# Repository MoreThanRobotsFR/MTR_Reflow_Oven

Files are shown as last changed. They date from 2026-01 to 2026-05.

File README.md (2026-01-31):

# MTR Reflow Oven

**MTR Reflow Oven** is a comprehensive hardware and firmware project designed to control a reflow oven for PCB assembly. This repository contains the custom PCB design, the firmware for the RP2040 microcontroller, and a companion PC configurator tool.

## Repository Structure

*   **`Firmware/`**
    *   **`mtr_reflow_oven/`**: The core C++ firmware for the RP2040 microcontroller. It handles temperature PID control, user interface (LVGL), and profile management.
    *   **`Configurator/`**: A Python-based desktop application for creating and managing reflow profiles and configuring device settings.
*   **`Hardware/`**
    *   Contains the KiCad project files (`.kicad_pcb`, `.kicad_sch`) for the custom controller board.

## Getting Started

### Hardware
The `Hardware` directory contains the complete KiCad project. You can open `Hardware/MTR_Reflow_Oven.kicad_pro` with [KiCad 8.0+](https://www.kicad.org/) to view or modify the schematics and PCB layout.

### Firmware (RP2040)
The firmware is built using the Raspberry Pi Pico SDK.

**Prerequisites:**
*   CMake
*   Arm GNU Toolchain (`arm-none-eabi-gcc`)
*   Pico SDK

**Build Instructions:**
1.  Navigate to the firmware directory:
    ```bash
    cd Firmware/mtr_reflow_oven
    ```
2.  Create a build directory:
    ```bash
    mkdir build
    cd build
    ```
3.  Configure and build:
    ```bash
    cmake ..
    make
    ```
4.  Flash the resulting `.uf2` file to your RP2040 device.

### Configurator (PC Software)
The configurator allows you to easily edit reflow profiles.

**Prerequisites:**
*   Python 3.x
*   Required packages (see `requirements.txt` if available, or manually install common dependencies like `pyserial`, `tkinter`/`customtkinter`).

**Running:**
```bash
cd Firmware/Configurator
python reflow_configurator.py
```

## License
[License Information Here]

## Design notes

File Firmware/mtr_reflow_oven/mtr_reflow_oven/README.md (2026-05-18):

# MTR Reflow Oven Controller

Firmware for the MoreThanRobotsFR (MTR) Reflow Oven, based on the Raspberry Pi Pico (RP2040).

## Overview

This project implements a complete reflow oven controller utilizing FreeRTOS for task management and LVGL for the graphical user interface. It is designed to run on the RP2040 microcontroller and controls up to two solid-state relays (SSRs) to manage heating elements using a custom PID control loop.

## Key Features

- **Microcontroller**: RP2040 (Raspberry Pi Pico)
- **Real-Time OS**: FreeRTOS
- **User Interface**: 
  - SPI Display (e.g., ST7796) driven by the LVGL graphics library
  - Navigation via Rotary Encoder and tactile buttons
  - Multi-screen UI (Dashboard, Profile Selection, Settings, Manual Control)
- **Temperature Sensing**: Support for up to two MCP9600 Thermocouple Amplifiers via I2C
- **Heater Control**: 
  - Dual PWM outputs for SSR (Solid State Relay) control
  - Configurable PID loop for precise temperature tracking
- **Storage**: SD Card support (FatFS over SPI) for loading JSON-based reflow profiles and saving system configurations
- **Feedback**: 
  - WS2812B RGB LED status indicator (using PIO)
  - Passive buzzer for audible alerts

## Hardware Configuration

The pinout and hardware settings are defined in `board_config.h`. 

Key pin assignments:
- **Display (SPI0)**: SCK (18), MOSI (19), MISO (20), CS (21), DC (25), RST (24), Backlight (23)
- **SD Card (SPI0)**: CS (22)
- **Sensors (I2C0)**: SDA (4), SCL (5)
- **Heaters**: SSR1 (26), SSR2 (27)
- **Inputs**: 
  - Rotary Encoder: DT (6), CLK (7), SW (8)
  - Buttons: BTN1 (0), BTN2 (1)
- **Outputs**: WS2812B LED (9), Buzzer (28)

## Build Instructions

This project uses CMake and requires the Raspberry Pi Pico SDK.

1. Ensure you have the [Raspberry Pi Pico SDK](https://github.com/raspberrypi/pico-sdk) installed and the `PICO_SDK_PATH` environment variable set.
2. Initialize and build the project:
   ```bash
   mkdir build
   cd build
   cmake ..
   make # or ninja, depending on your environment
   ```
3. Flash the resulting `.uf2` file to your Pico by holding the BOOTSEL button while plugging it in, then dragging the file to the `RPI-RP2` drive.

## Configuration & Profiles

- **System Config**: Settings such as PID tuning parameters, display orientation, and hardware flags are stored on the SD Card at `/config/system.json`.
- **Reflow Profiles**: Custom temperature profiles (e.g., SAC305) can be loaded from the SD Card in JSON format. They define specific heating segments (Preheat, Soak, Ramp, Reflow) with target temperatures and durations.

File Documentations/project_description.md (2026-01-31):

# Projet : Four de Refusion de Précision (RP2040, FreeRTOS, LVGL)

## 1. Objectif Global

Transformer un four via un contrôleur basé sur **RP2040** en une station de refusion performante. Le système se distingue par :

* Un **suivi thermique haute précision** via capteurs I2C dédiés (MCP9600).
* Une gestion **multi-zones** (2 éléments chauffants pilotables indépendamment).
* Une architecture logicielle **FreeRTOS** robuste (séparation UI / Contrôle / Sécurité).
* Des **profils de refusion flexibles** (nombre illimité de paliers/segments via SD).
* Une interface graphique (UI) fluide sous **LVGL**.

## 2. Matériel & Interfaces (Mise à jour Câblage Réel)

### 2.1 Cœur & Bus

* **MCU** : Raspberry Pi RP2040 (Dual-core ARM Cortex-M0+ @ 133MHz).
* **Bus SPI0** (Partagé) : Écran TFT + Carte SD. Nécessite une gestion rigoureuse des Chip Select (CS) et du timing.
* **Bus I2C** : Capteurs de température MCP9600 (Adresses distinctes requises).
* **Bus 1-Wire** : Sonde d'ambiance/calibration DS18B20.

### 2.2 Entrées Utilisateur (HMI)

Le panneau de commande dispose de **4 boutons physiques** et **1 encodeur rotatif** :

* **Boutons Nav** : 3 boutons dédiés (GPIO 0, 1, 2) pour actions rapides (Start, Stop, Menu) ou navigation contextuelle.
* **Encodeur** : Rotation (GPIO 6, 7) + Bouton intégré (GPIO 8) pour le réglage fin des valeurs.

### 2.3 Affichage & Feedback

* **Écran** : Module SPI (ex: ILI9341, ST7789) avec contrôle complet (Backlight, DC, Reset).
* **LEDs Statut** : Ruban/Module **WS2812B** (Smart LED) sur GPIO 9 pour coder l'état (Bleu=Cool, Orange=Preheat, Rouge=Reflow, Vert=Complete).
* **Buzzer** : Buzzer actif ou passif (PWM) sur GPIO 28 pour alarmes et bips IHM.

### 2.4 Thermométrie & Puissance

* **Capteur T1 (Principal)** : MCP9600 (Thermocouple convertisseur I2C). Haute précision, compensation de soudure froide intégrée.
* **Capteur T2 (Optionnel)** : MCP9600 secondaire. Le système doit scanner l'I2C au démarrage ; si absent, le four fonctionne en mode "Single Sensor".
* **Sécurité Hardware** : Les broches d'alerte (Alert 1-4) des MCP9600 sont câblées aux GPIOs RP2040. Cela permet de déclencher des interruptions immédiates en cas de surchauffe, sans attendre la boucle de lecture I2C.
* **Actionneurs Chauffe** :
* **SSR 1 (GPIO 26)** : Élément chauffant principal.
* **SSR 2 (GPIO 27)** : Élément chauffant secondaire (Boost ou zone distincte).

---

## 3. Mapping GPIO Définitif

Ce tableau respecte scrupuleusement le fichier `Extrait du cablage réal.csv`.

| GPIO | Fonction Label | Type Signal | Description Technique / Usage |
| --- | --- | --- | --- |
| **0** | BTN1 | Input (IRQ) | Bouton Façade 1 (Navigation/Action) |
| **1** | BTN2 | Input (IRQ) | Bouton Façade 2 (Navigation/Action) |
| **2** | BTN3 | Input (IRQ) | Bouton Façade 3 (Navigation/Action) |
| **3** | SD_CD | Input | **SD Card Detect**. Low = Carte présente. |
| **4** | I2C_SDA | I2C Data | Bus I2C pour MCP9600 (Sensor 1 & 2). |
| **5** | I2C_SCL | I2C Clock | Bus I2C pour MCP9600 (Sensor 1 & 2). |
| **6** | ROT_DT | Input (IRQ) | Encodeur Phase B (Data). |
| **7** | ROT_CLK | Input (IRQ) | Encodeur Phase A (Clock). |
| **8** | ROT_BTN | Input (IRQ) | Bouton poussoir de l'encodeur. |
| **9** | WS_LED | Output (Data) | Signal **WS2812B** (Neopixel) pour feedback visuel. |
| **10** | T1_ALT4 | Input (IRQ) | MCP9600 T1 Alert 4 (Seuil critique Hard). |
| **11** | T1_ALT3 | Input (IRQ) | MCP9600 T1 Alert 3. |
| **12** | T1_ALT2 | Input (IRQ) | MCP9600 T1 Alert 2. |
| **13** | T1_ALT1 | Input (IRQ) | MCP9600 T1 Alert 1 (Seuil pré-alerte). |
| **14** | T2_ALT4 | Input (IRQ) | MCP9600 T2 Alert 4 (Si T2 présent). |
| **15** | T2_ALT3 | Input (IRQ) | MCP9600 T2 Alert 3. |
| **16** | T2_ALT2 | Input (IRQ) | MCP9600 T2 Alert 2. |
| **17** | T2_ALT1 | Input (IRQ) | MCP9600 T2 Alert 1. |
| **18** | SPI_SCK | SPI0 Clock | Horloge partagée Écran + SD. |
| **19** | SPI_MOSI | SPI0 TX | Données sortantes (Vers Écran + SD). |
| **20** | SPI_MISO | SPI0 RX | Données entrantes (Depuis SD uniquement). |
| **21** | SCR_CS | Output | **Chip Select Écran**. |
| **22** | SD_CS | Output | **Chip Select SD Card** (Note: Label SD_DAT3/CS). |
| **23** | SCR_BL | Output (PWM) | Backlight écran (dimming possible). |
| **24** | SCR_RST | Output | Reset Hardware Écran. |
| **25** | SCR_DC | Output | Data/Command Écran. |
| **26** | HEAT1 | Output (PWM) | Pilotage SSR 1 (Résistance principale). |
| **27** | HEAT2 | Output (PWM) | Pilotage SSR 2 (Résistance secondaire). |
| **28** | BUZZER | Output (PWM) | Buzzer (Tones passifs ou Active High). |
| **29** | 1-WIRE | In/Out | Bus OneWire pour DS18B20 (Ambiante/Ref). |

---

## 4. Fonctionnalités Logicielles Avancées

### 4.1 Profils Thermiques Dynamiques ("Flexible Steps")

Contrairement à une structure rigide (Preheat/Soak/Reflow), le moteur de profil lira une liste de **segments**. Cela permet de créer des profils complexes (ex: recuit lent, double refusion, séchage PCB).

* **Types de segments supportés** :
* `RAMP` : Atteindre une T° cible avec une pente donnée (°C/s).
* `STEP` : Saut immédiat de consigne (step response).
* `HOLD` : Maintenir la T° pendant X secondes.

* **Chargement** : Parsing JSON depuis la carte SD.

### 4.2 Gestion Hardware "Safe"

* **Détection T2** : Au boot, ping I2C sur l'adresse de T2. Si ACK → Activation T2. Sinon → Ignorer T2 et masquer les infos T2 sur l'UI.
* **Interruptions MCP9600** : Configuration des registres MCP9600 pour trigger les pins ALT (GPIO 10-17) si T° > 260°C (hard limit). Une ISR sur ces pins coupe immédiatement les SSR, bypassant le RTOS en cas de plantage tâche.

### 4.3 Contrôle PID & PWM

* **PWM Lente** : Les SSR Zéro-crossing n'aiment pas le PWM rapide. On utilisera un PWM logiciel ou hardware à très basse fréquence (ex: 2Hz à 5Hz) ou un algorithme de Bresenham sur une base de temps de 100ms.
* **Dual PID** : Possibilité d'avoir des paramètres PID différents pour SSR1 et SSR2, ou de coupler SSR2 en mode "Esclave" (ex: SSR2 = 80% de SSR1 pour homogénéiser).

---

## 5. Architecture Système (FreeRTOS)

L'absence de Servo simplifie la sortie, mais l'ajout de la gestion SPI partagée et des interruptions MCP demande de la rigueur.

### 5.1 Tâches (Tasks)

| Priorité | Tâche | Stack | Description |
| --- | --- | --- | --- |
| **High (5)** | `Alert_Handling` | Minimal | Traitement des interruptions GPIO (MCP9600 ALT pins) et Watchdog. Arrêt d'urgence. |
| **High (4)** | `Sensor_Poller` | 3 KB | Lecture I2C (MCP9600) et 1-Wire. Conversion des données brutes. Gestion des erreurs de lecture. |
| **Med (3)** | `PID_Loop` | 2 KB | Calcul de l'erreur, PID, output PWM vers SSRs. Cycle fixe (ex: 200ms). |
| **Med (3)** | `App_Logic` | 4 KB | Machine d'états (Idle, Run, Cooldown). Orchestrateur principal. Parseur JSON. |
| **Low (2)** | `GUI_Task` | 8 KB | Gestion LVGL, rafraîchissement écran, lecture inputs (Queue events). |
| **Low (1)** | `Disk_Logger` | 4 KB | Écriture asynchrone des logs CSV sur SD (pour ne pas bloquer les tâches critiques). |

### 5.2 Gestion des Ressources (Mutex & Queues)

* **`mtx_SPI0` (CRITIQUE)** : L'écran et la SD sont sur le même bus.
* La tâche `GUI_Task` doit prendre ce mutex avant de dessiner.
* La tâche `Disk_Logger` (et le chargeur de profil `App_Logic`) doit prendre ce mutex avant tout accès fichier.
* *Stratégie* : Utiliser le DMA pour l'écran pour minimiser le temps de blocage du CPU, mais le Mutex reste obligatoire pour l'accès bus.

* **`mtx_I2C`** : Protection d'accès aux capteurs MCP9600.
* **`q_SensorData`** : Structure contenant `{temp1, temp2, temp_amb, status_flags}` envoyée par *Sensor_Poller* vers *PID_Loop* et *GUI*.

---

## 6. Structure des Fichiers (Carte SD)

### 6.1 Format de Profil (`/profiles/sac305.json`)

Structure mise à jour pour permettre un nombre illimité d'étapes.

```json
{
  "meta": {
    "name": "SAC305 Standard",
    "description": "Profil sans plomb classique",
    "author": "User"
  },
  "safety": {
    "max_temp": 255,
    "max_slope": 3.0
  },
  "segments": [
    { "type": "ramp", "end_temp": 150, "slope": 1.5, "note": "Preheat" },
    { "type": "hold", "duration_s": 90,  "temp": 150, "note": "Soak" },
    { "type": "ramp", "end_temp": 217, "slope": 2.5, "note": "Ramp to Reflow" },
    { "type": "ramp", "end_temp": 245, "slope": 1.0, "note": "Peak Reflow" },
    { "type": "hold", "duration_s": 20,  "temp": 245, "note": "Liquid Time" },
    { "type": "ramp", "end_temp": 50,  "slope": -2.0, "note": "Cooling" }
  ]
}

```

### 6.2 Fichier de Configuration (`/config/system.json`)

```json
{
  "hardware": {
    "enable_sensor2_check": true,
    "screen_orientation": 1,
    "buzzer_volume": 80
  },
  "pid_params": {
    "ssr1": { "kp": 15.0, "ki": 0.05, "kd": 80.0 },
    "ssr2": { "kp": 10.0, "ki": 0.05, "kd": 50.0 }
  },
  "calibration": {
    "t1_offset": -1.5,
    "t2_offset": 0.0
  }
}

```

---

## 7. Machine d'États Révisée

1. **INIT** : Setup GPIO, détection T2 (I2C), montage SD (SD_CD check), init écran.
2. **IDLE** : Attente utilisateur. Lecture T° ambiante. Affichage liste profils.
3. **PRE_CHECK** : Vérification intégrité capteurs (pas de court-circuit MCP9600), porte fermée (si capteur ajouté futur), température de départ < 50°C.
4. **RUNNING** : Exécution du tableau `segments`.
* Calcul de la `Target_Temp` courante par interpolation temporelle.
* PID calcule `% Power`.
* Update Graphique.

5. **COOLDOWN** : Fin du profil ou annulation manuelle. SSR OFF. Affichage "HOT" en rouge/orange sur LED WS2812B tant que T > 50°C. Buzzer intermittent.
6. **FAULT** : Déclenché par ISR (Pins ALT) ou timeout logiciel. SSR OFF hard (GPIO low). Buzzer continu. Log de l'erreur.

---

## 8. Roadmap Technique & Étapes Clés

1. **Low-Level Drivers (HAL)** :
* Valider le SPI partagé : Dessiner sur l'écran puis écrire un fichier texte sur la SD dans une boucle simple sans corruption.
* Valider I2C MCP9600 : Lire la T° et configurer les registres d'alerte pour tester le déclenchement des GPIO 10-13.

2. **Intégration FreeRTOS Base** :
* Lancer LVGL dans sa tâche.
* Lancer le logger SD dans sa tâche.
* Vérifier que les inputs (Encodeur/Boutons) via interruptions mettent bien à jour l'UI.

3. **Moteur Thermique** :
* Implémenter le parseur de segments JSON.
* Coder la boucle PID.
* Tester avec une consigne fixe (Mode Manuel) avant de lancer un profil.

4. **Raffinement** :
* Logique de détection automatique du Capteur 2.
* Effets LED WS2812B (Dégradés de couleur selon T°).
* Tuning PID.

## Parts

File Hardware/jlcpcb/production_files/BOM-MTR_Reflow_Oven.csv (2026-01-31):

Comment | Designator | Footprint | LCSC | Quantity
0.1uF | C17,C18,C19,C23,C24,C3,C4 | R_0402_1005Metric | C60474 | 7
100R | R16,R17,R19,R20 | R_0402_1005Metric | C106232 | 4
100nF | C10,C11,C12,C13,C14,C15,C16,C5,C6,C8 | C_0402_1005Metric | C1525 | 10
10k |  | R_0402_1005Metric | C60490 | 0
18p | C1,C2 | C_0402_1005Metric | C33149 | 2
1M | R18,R21 | R_0402_1005Metric | C138033 | 2
1k | R1,R5 | R_0402_1005Metric | C106235 | 2
1uF | C21,C22,C7,C9 | C_0402_1005Metric | C14445 | 4
27.4R | R2,R3 | R_0402_1005Metric | C31439 | 2
2M | R22,R23,R24,R25 | R_0402_1005Metric | C11512 | 4
4.7k | R10,R11,R13,R14,R15,R4,R7,R8,R9 | R_0402_1005Metric | C105871 | 9
5.1k | R26,R27 | R_0402_1005Metric | C105871 | 2
ABM8-272-T3 | Y1 | CRYSTAL-SMD_4P-L3.2-W2.5-BL | C20625731 | 1
AO3401A | Q1 | SOT-23-3 | C15127 | 1
B3F-4055 | SW4,SW5 | KEY-TH_4P-L12.0-W12.0-P5.00-LS13.4-EH | C84931 | 2
Boot | SW1 | SW-SMD_L4.0-W3.0-LS5.0 | C2888420 | 1
DS18B20 | U4 | TO-92_Inline | C9753 | 1
FST-9018 | BZ1 | BUZ-SMD_FST-9018 | C391035 | 1
MCP9600T-E/MX | U5,U6 | QFN-20-1EP_5x5mm_P0.65mm_EP3.35x3.35mm_ThermalVias | C623918 | 2
RP2040 | U1 | QFN-56-1EP_7x7mm_P0.4mm_EP3.2x3.2mm_ThermalVias | C2040 | 1
Reset | SW2 | SW-SMD_L4.0-W3.0-LS5.0 | C2888420 | 1
RotaryEncoder_Switch_MP | SW3 | SW-TH_EC11XXXXXXXX | C470742 | 1
TF-01A_C2889258 | Card1 | TF-SMD_TF-02 | C2889258 | 1
TLV76733DRVR | U3 | WSON-6_L2.0-W2.0-P0.65-TL-EP | C2848334 | 1
TPS22810DRVR | U7,U8 | WSON-6-1EP_2x2mm_P0.65mm_EP1x1.6mm | C527679 | 2
USB_C_Receptacle_USB2.0 | J2 | USB_C_Receptacle_HRO_TYPE-C-31-M-12 | C165948 | 1
W25Q128JVS | U2 | SOIC-8_5.3x5.3mm_P1.27mm | C97521 | 1
WS2812B-B/W | LED1,LED2 | LED-SMD_4P-L5.0-W5.0-TL_WS2812B-B | C2761795 | 2
PINHD_1x8_Male | J1 | PinHeader_1x08_P2.54mm_Vertical |  | 1

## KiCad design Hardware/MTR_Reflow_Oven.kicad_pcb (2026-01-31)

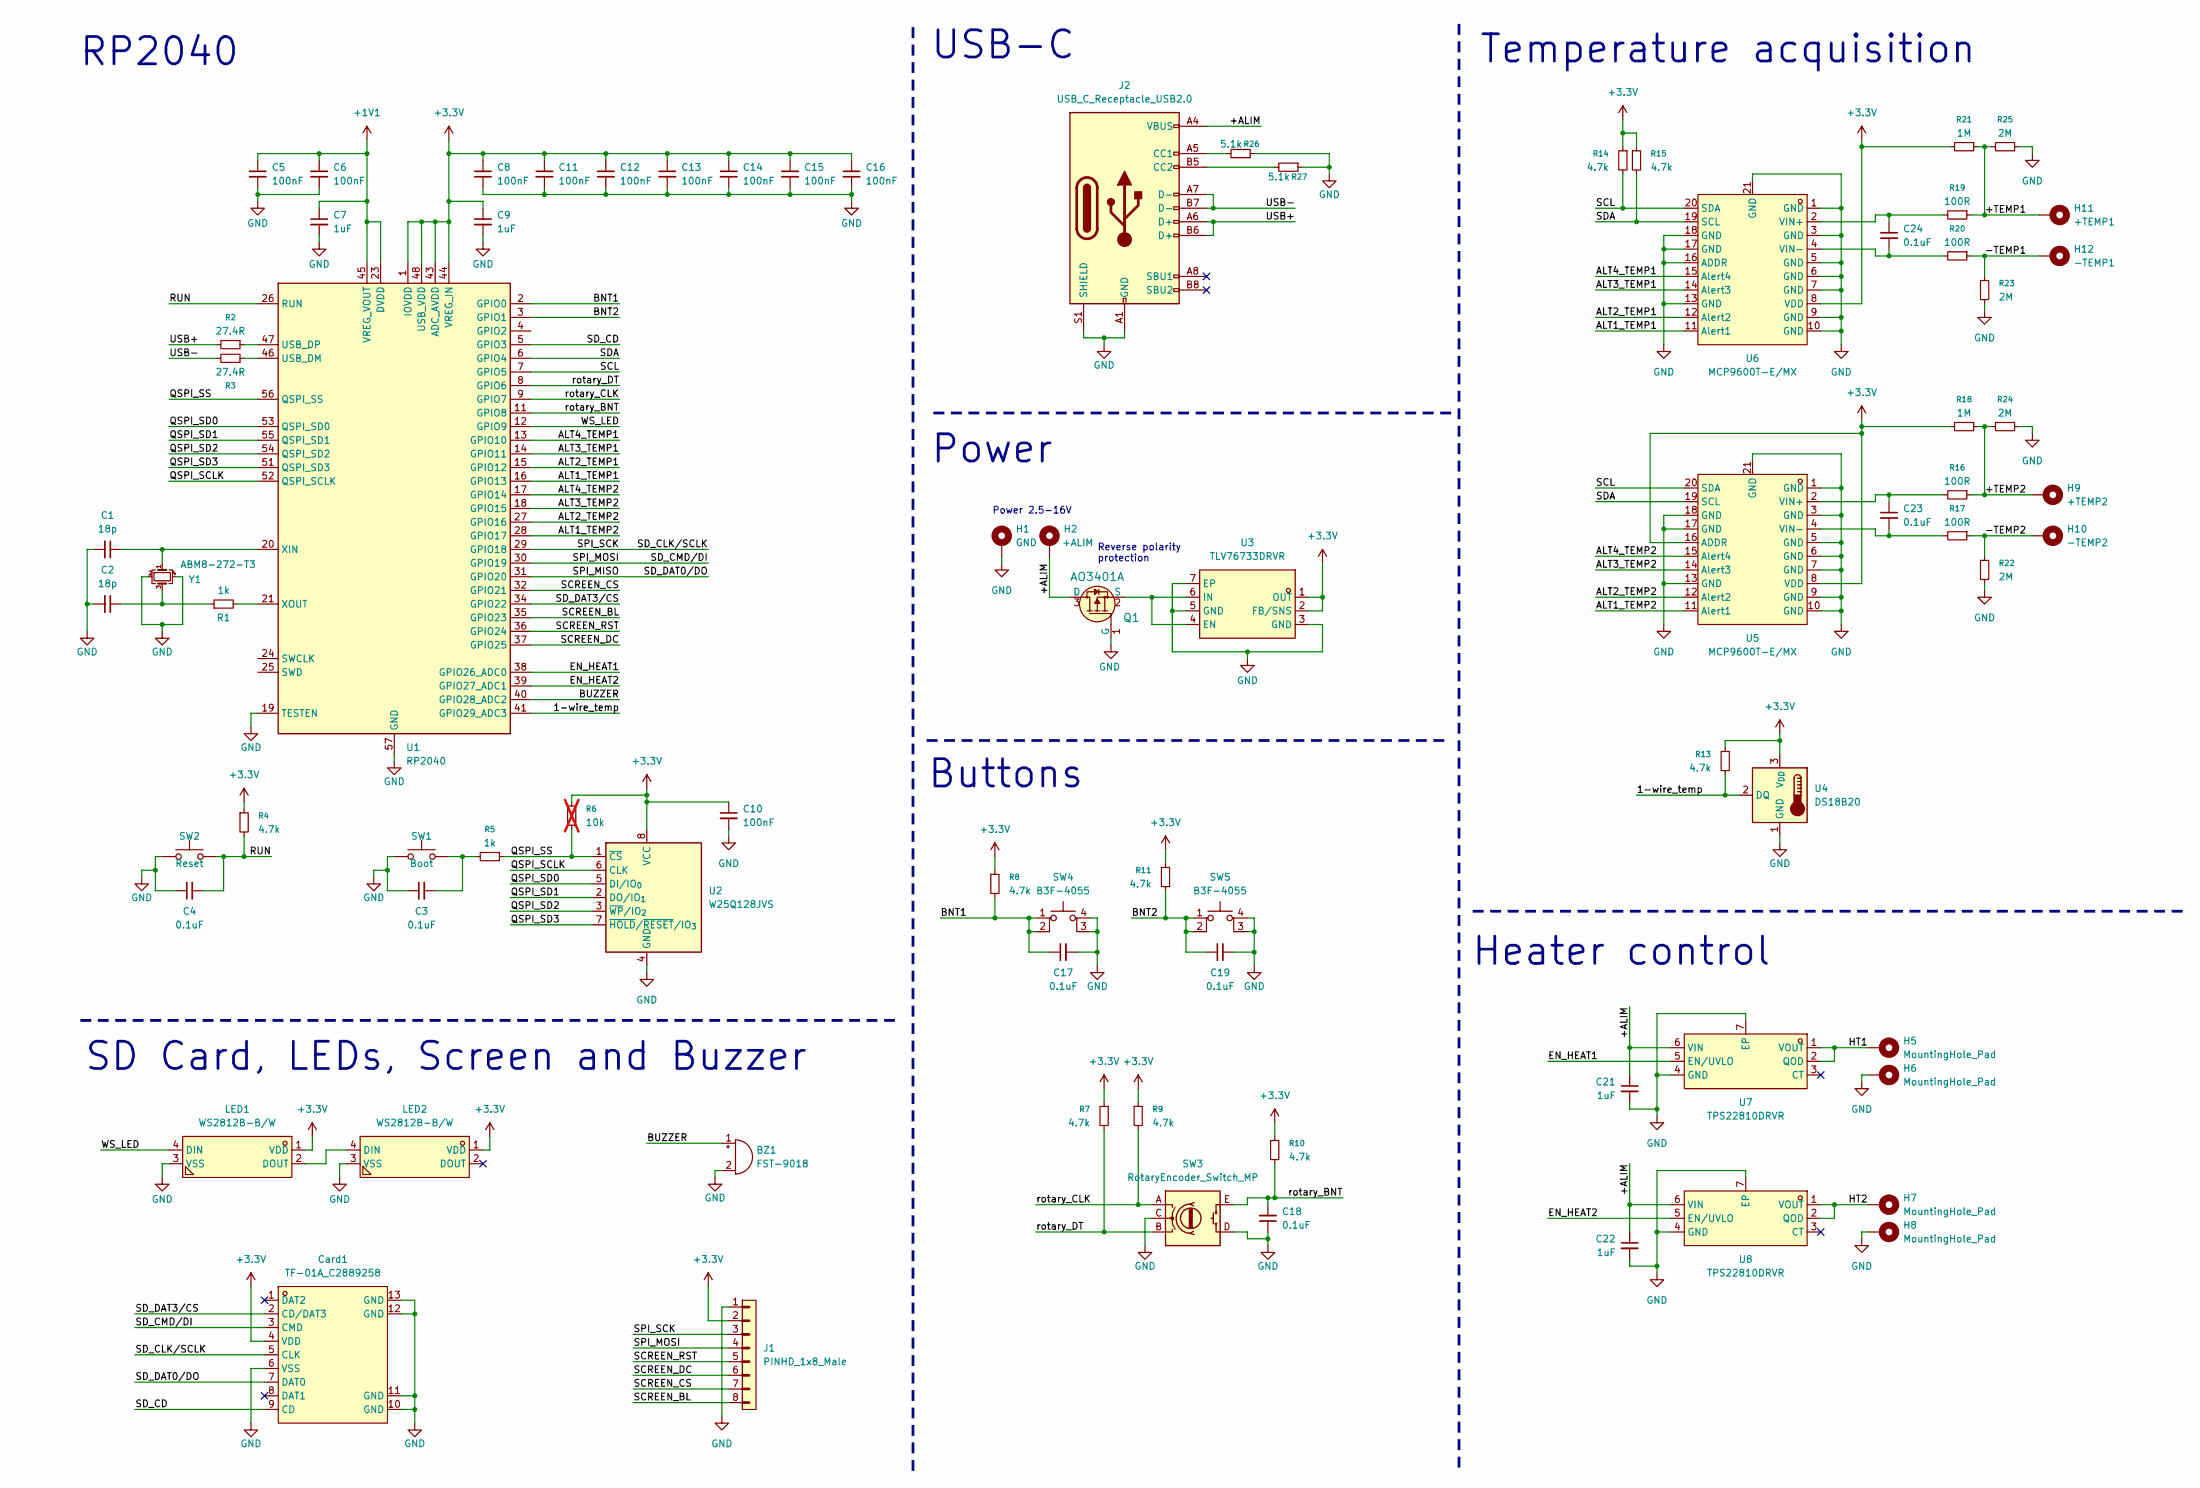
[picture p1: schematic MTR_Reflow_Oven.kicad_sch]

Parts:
BZ1: FST-9018; BUZ-SMD_FST-9018; LCSC Part C391035
C1, C2: 18p; C_0402_1005Metric; LCSC C33149
C3, C4, C17, C18, C19: 0.1uF; R_0402_1005Metric; LCSC C60474
C5, C6, C8, C10, C11, C12, C13, C14, C15, C16: 100nF; C_0402_1005Metric; LCSC C1525
C7, C9, C21, C22: 1uF; C_0402_1005Metric; LCSC C14445
C23, C24: 0.1uF; C_0402_1005Metric; LCSC C60474
Card1: TF-01A_C2889258; TF-SMD_TF-02; LCSC Part C2889258
H1: GND; MountingHole_2.2mm_M2_Pad
H2: +ALIM; MountingHole_2.2mm_M2_Pad
H5, H6, H7, H8: MountingHole_Pad; MountingHole_2.2mm_M2_Pad
H9: +TEMP2; MountingHole_2.2mm_M2_Pad
H10: -TEMP2; MountingHole_2.2mm_M2_Pad
H11: +TEMP1; MountingHole_2.2mm_M2_Pad
H12: -TEMP1; MountingHole_2.2mm_M2_Pad
J1: PINHD_1x8_Male; PinHeader_1x08_P2.54mm_Vertical
J2: USB_C_Receptacle_USB2.0; USB_C_Receptacle_HRO_TYPE-C-31-M-12; LCSC C165948
LED1, LED2: WS2812B-B/W; LED-SMD_4P-L5.0-W5.0-TL_WS2812B-B; LCSC Part C2761795
Q1: AO3401A; SOT-23-3; MPN AO3401A; Digi-Key_PN 785-1001-1-ND
R1, R5: 1k; R_0402_1005Metric; LCSC C106235
R2, R3: 27.4R; R_0402_1005Metric; LCSC C31439
R4, R7, R8, R9, R10, R11, R13, R14, R15: 4.7k; R_0402_1005Metric; LCSC C105871
R6: 10k; R_0402_1005Metric; LCSC C60490; not fitted
R16, R17, R19, R20: 100R; R_0402_1005Metric; LCSC C106232
R18, R21: 1M; R_0402_1005Metric; LCSC C138033
R22, R23, R24, R25: 2M; R_0402_1005Metric; LCSC C11512
R26, R27: 5.1k; R_0402_1005Metric; LCSC C105871
SW1: Boot; SW-SMD_L4.0-W3.0-LS5.0; LCSC C2888420
SW2: Reset; SW-SMD_L4.0-W3.0-LS5.0; LCSC C2888420
SW3: RotaryEncoder_Switch_MP; SW-TH_EC11XXXXXXXX; LCSC C470742
SW4, SW5: B3F-4055; KEY-TH_4P-L12.0-W12.0-P5.00-LS13.4-EH; LCSC C84931
U1: RP2040; QFN-56-1EP_7x7mm_P0.4mm_EP3.2x3.2mm_ThermalVias; LCSC C2040
U2: W25Q128JVS; SOIC-8_5.3x5.3mm_P1.27mm; LCSC C97521
U3: TLV76733DRVR; WSON-6_L2.0-W2.0-P0.65-TL-EP; LCSC Part C2848334
U4: DS18B20; TO-92_Inline; LCSC C9753
U5, U6: MCP9600T-E/MX; QFN-20-1EP_5x5mm_P0.65mm_EP3.35x3.35mm_ThermalVias; LCSC Part C623918
U7, U8: TPS22810DRVR; WSON-6-1EP_2x2mm_P0.65mm_EP1x1.6mm; LCSC Part C527679
Y1: ABM8-272-T3; CRYSTAL-SMD_4P-L3.2-W2.5-BL; LCSC C20625731

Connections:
+1V1: C5.1, C6.1, C7.1, U1.23 (DVDD), U1.45 (VREG_VOUT), U1.50 (DVDD)
+3.3V: C8.1, C9.1, C10.1, C11.1, C12.1, C13.1, C14.1, C15.1, C16.1, Card1.4 (VDD), J1.2, LED1.1 (VDD), LED2.1 (VDD), R4.1, R6.1, R7.1, R8.1, R9.1, R10.1, R11.1, R13.1, R14.1, R15.1, R18.2, R21.2, U1.1 (IOVDD), U1.10 (IOVDD), U1.22 (IOVDD), U1.33 (IOVDD), U1.42 (IOVDD), U1.43 (ADC_AVDD), U1.44 (VREG_IN), U1.48 (USB_VDD), U1.49 (IOVDD), U2.8 (VCC), U3.1 (OUT), U3.2 (FB/SNS), U4.3 (V_{DD}), U5.8 (VDD), U5.16 (ADDR), U6.8 (VDD)
/1-wire_temp: R13.2, U1.41 (GPIO29_ADC3), U4.2 (DQ)
/+ALIM: C21.1, C22.1, H2.1, J2.A4 (VBUS), J2.A9 (VBUS), J2.B4 (VBUS), J2.B9 (VBUS), Q1.3 (D), U7.6 (VIN), U8.6 (VIN)
/+TEMP1: H11.1, R19.1, R21.1, R25.2
/+TEMP2: H9.1, R16.1, R18.1, R24.2
/-TEMP1: H12.1, R20.1, R23.1
/-TEMP2: H10.1, R17.1, R22.1
/ALT1_TEMP1: U1.16 (GPIO13), U6.11 (Alert1)
/ALT1_TEMP2: U1.28 (GPIO17), U5.11 (Alert1)
/ALT2_TEMP1: U1.15 (GPIO12), U6.12 (Alert2)
/ALT2_TEMP2: U1.27 (GPIO16), U5.12 (Alert2)
/ALT3_TEMP1: U1.14 (GPIO11), U6.14 (Alert3)
/ALT3_TEMP2: U1.18 (GPIO15), U5.14 (Alert3)
/ALT4_TEMP1: U1.13 (GPIO10), U6.15 (Alert4)
/ALT4_TEMP2: U1.17 (GPIO14), U5.15 (Alert4)
/BNT1: C17.1, R8.2, SW4.1, SW4.2, U1.2 (GPIO0)
/BNT2: C19.1, R11.2, SW5.1, SW5.2, U1.3 (GPIO1)
/BUZZER: BZ1.1 (+), U1.40 (GPIO28_ADC2)
/EN_HEAT1: U1.38 (GPIO26_ADC0), U7.5 (EN/UVLO)
/EN_HEAT2: U1.39 (GPIO27_ADC1), U8.5 (EN/UVLO)
/HT1: H5.1, U7.1 (VOUT), U7.2 (QOD)
/HT2: H7.1, U8.1 (VOUT), U8.2 (QOD)
/QSPI_SCLK: U1.52 (QSPI_SCLK), U2.6 (CLK)
/QSPI_SD0: U1.53 (QSPI_SD0), U2.5 (DI/IO_{0})
/QSPI_SD1: U1.55 (QSPI_SD1), U2.2 (DO/IO_{1})
/QSPI_SD2: U1.54 (QSPI_SD2), U2.3 (~WP/IO_{2})
/QSPI_SD3: U1.51 (QSPI_SD3), U2.7 (~HOLD/~RESET/IO_{3})
/QSPI_SS: R5.1, R6.2, U1.56 (QSPI_SS), U2.1 (~CS)
/RUN: C4.2, R4.2, SW2.2, U1.26 (RUN)
/SCL: R14.2, U1.7 (GPIO5), U5.20 (SDA), U6.20 (SDA)
/SCREEN_BL: J1.8, U1.35 (GPIO23)
/SCREEN_CS: J1.7, U1.32 (GPIO21)
/SCREEN_DC: J1.6, U1.37 (GPIO25)
/SCREEN_RST: J1.5, U1.36 (GPIO24)
/SDA: R15.2, U1.6 (GPIO4), U5.19 (SCL), U6.19 (SCL)
/SD_CD: Card1.9 (CD), U1.5 (GPIO3)
/SD_CLK/SCLK: Card1.5 (CLK), J1.3, U1.29 (GPIO18)
/SD_CMD/DI: Card1.3 (CMD), J1.4, U1.30 (GPIO19)
/SD_DAT0/DO: Card1.7 (DAT0), U1.31 (GPIO20)
/SD_DAT3/CS: Card1.2 (CD/DAT3), U1.34 (GPIO22)
/USB+: J2.A6 (D+), J2.B6 (D+), R2.2
/USB-: J2.A7 (D-), J2.B7 (D-), R3.2
/WS_LED: LED1.4 (DIN), U1.12 (GPIO9)
/rotary_BNT: C18.2, R10.2, SW3.E (S1), U1.11 (GPIO8)
/rotary_CLK: R9.2, SW3.A, U1.9 (GPIO7)
/rotary_DT: R7.2, SW3.B, U1.8 (GPIO6)
GND: BZ1.2 (-), C1.2, C2.2, C3.1, C4.1, C5.2, C6.2, C7.2, C8.2, C9.2, C10.2, C11.2, C12.2, C13.2, C14.2, C15.2, C16.2, C17.2, C18.1, C19.2, C21.2, C22.2, Card1.6 (VSS), Card1.10 (GND), Card1.11 (GND), Card1.12 (GND), Card1.13 (GND), H1.1, H6.1, H8.1, J1.1, J2.A1 (GND), J2.A12 (GND), J2.B1 (GND), J2.B12 (GND), J2.S1 (SHIELD), LED1.3 (VSS), LED2.3 (VSS), Q1.1 (G), R22.2, R23.2, R24.1, R25.1, R26.1, R27.1, SW1.1, SW2.1, SW3.C, SW3.D (S2), SW4.3 (K), SW4.4 (A), SW5.3 (K), SW5.4 (A), U1.19 (TESTEN), U1.57 (GND), U2.4 (GND), U3.3 (GND), U3.5 (GND), U3.7 (EP), U4.1 (GND), U5.1 (GND), U5.3 (GND), U5.5 (GND), U5.6 (GND), U5.7 (GND), U5.9 (GND), U5.10 (GND), U5.13 (GND), U5.17 (GND), U5.18 (GND), U5.21 (GND), U6.1 (GND), U6.3 (GND), U6.5 (GND), U6.6 (GND), U6.7 (GND), U6.9 (GND), U6.10 (GND), U6.13 (GND), U6.16 (ADDR), U6.17 (GND), U6.18 (GND), U6.21 (GND), U7.4 (GND), U7.7 (EP), U8.4 (GND), U8.7 (EP), Y1.2, Y1.4
unnamed: C2.1, R1.1, Y1.3
unnamed: C3.2, R5.2, SW1.2
unnamed: J2.A5 (CC1), R26.2
unnamed: J2.B5 (CC2), R27.2
unnamed: LED1.2 (DOUT), LED2.4 (DIN)
unnamed: Q1.2 (S), U3.4 (EN), U3.6 (IN)
unnamed: R3.1, U1.46 (USB_DM)
unnamed: R2.1, U1.47 (USB_DP)
unnamed: C1.1, U1.20 (XIN), Y1.1
unnamed: R1.2, U1.21 (XOUT)
unnamed: C23.1, R16.2, U5.2 (VIN+)
unnamed: C23.2, R17.2, U5.4 (VIN-)
unnamed: C24.1, R19.2, U6.2 (VIN+)
unnamed: C24.2, R20.2, U6.4 (VIN-)

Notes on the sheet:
Power
Temperature acquisition
USB-C
Heater control
SD Card, LEDs, Screen and Buzzer
Reverse polarity protection
Buttons
Power 2.5-16V
RP2040

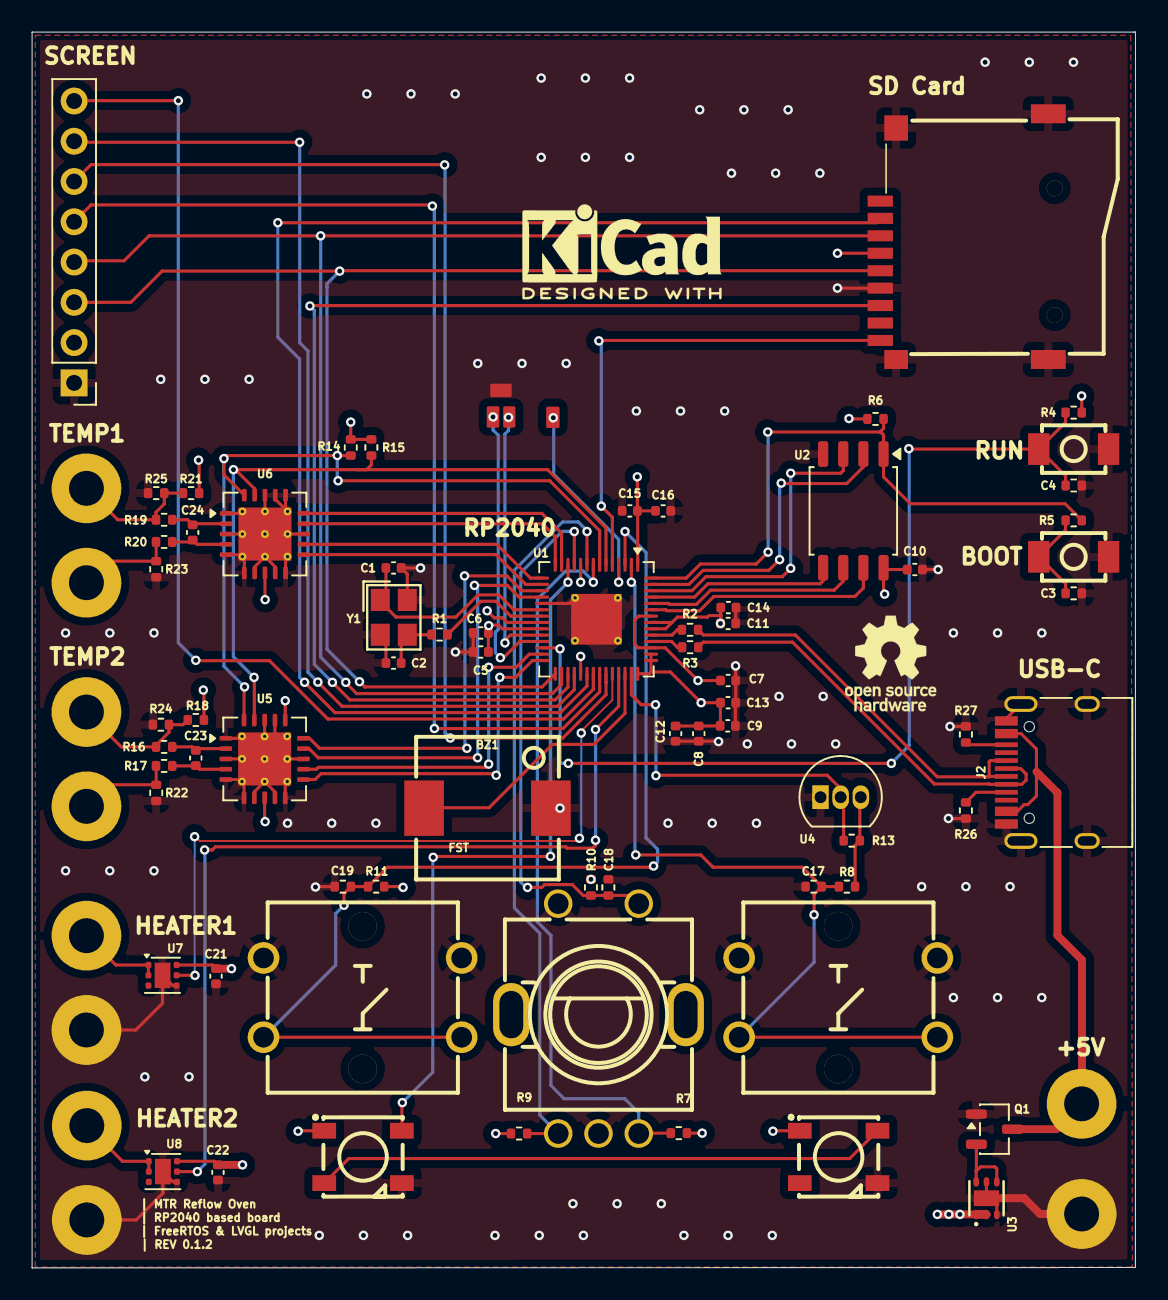
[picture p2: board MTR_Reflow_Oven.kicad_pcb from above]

Board: 4 copper layers, 69.6 x 77.9 mm, 80 parts (0 on the bottom side), 62 nets.

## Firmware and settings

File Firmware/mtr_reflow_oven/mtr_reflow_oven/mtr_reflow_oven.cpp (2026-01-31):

#include <stdio.h>
#include <cstdlib>
#include <cmath>
#include "pico/stdlib.h"
#include "pico/multicore.h"
#include "hardware/spi.h"
#include "hardware/i2c.h"
#include "hardware/dma.h"
#include "hardware/gpio.h"

// FreeRTOS Headers
#include "FreeRTOS.h"
#include "task.h"
#include "queue.h"
#include "semphr.h"

// Project Headers
#include "board_config.h"
#include "project_defs.h"

// Library Headers
// #include "hagl_hal.h"

#include "lvgl.h"
#include <cwchar>
#include <cstring>
#include "ui/ui_manager.h"

// LVGL Tick Interface
extern "C" uint32_t my_tick_get(void) {
    return to_ms_since_boot(get_absolute_time());
}

#include "ff.h"
#include "diskio.h"
#include "sd_card.h"
#include "cJSON.h"
#include "hardware/pio.h"
#include "hardware/clocks.h"

// --- Project Definitions ---
// --- Project Definitions ---
// MAX_PROFILE_SEGMENTS moved to project_defs.h

// --- Helper Functions ---
uint32_t millis() {
    return to_ms_since_boot(get_absolute_time());
}

// Helper: Play tone for passive buzzer (blocking)
void play_tone(uint32_t freq_hz, uint32_t duration_ms) {
    if (freq_hz == 0) {
        sleep_ms(duration_ms);
        return;
    }
    
    uint32_t period_us = 1000000 / freq_hz;
    uint32_t half_period = period_us / 2;
    
    uint32_t end = millis() + duration_ms;
    while (millis() < end) {
        gpio_put(GPIO_BUZZER, 1);
        sleep_us(half_period);
        gpio_put(GPIO_BUZZER, 0);
        sleep_us(half_period);
    }
}

// --- Colors ---
#define TFT_BLACK   0x0000
#define TFT_WHITE   0xFFFF
#define TFT_RED     0xF800
#define TFT_GREEN   0x07E0
#define TFT_BLUE    0x001F
#define TFT_CYAN    0x07FF
#define TFT_MAGENTA 0xF81F
#define TFT_YELLOW  0xFFE0
#define TFT_ORANGE  0xFD20
#define TFT_GREY    0x8410



// --- UI Context ---
UIContext uiCtx;

// --- WS2812B PIO Program (Pre-compiled) ---
static const uint16_t ws2812_program_instructions[] = {
    0x6221, //  0: out    x, 1            side 0 [2] 
    0x1123, //  1: jmp    !x, 3           side 1 [1] 
    0x1400, //  2: jmp    0               side 1 [4] 
    0xa442, //  3: nop                    side 0 [4] 
};

static const struct pio_program ws2812_program = {
    .instructions = ws2812_program_instructions,
    .length = 4,
    .origin = -1,
};

void ws2812_program_init(PIO pio, uint sm, uint offset, uint pin, float freq, bool rgbw) {
    pio_gpio_init(pio, pin);
    pio_sm_set_consecutive_pindirs(pio, sm, pin, 1, true);

    pio_sm_config c = pio_get_default_sm_config();
    sm_config_set_sideset_pins(&c, pin);
    sm_config_set_sideset(&c, 1, false, false); // 1 sideset bit, not optional, not pindirs
    sm_config_set_out_shift(&c, false, true, rgbw ? 32 : 24);
    sm_config_set_fifo_join(&c, PIO_FIFO_JOIN_TX);
    sm_config_set_wrap(&c, offset, offset + 3); // wrap around all 4 instructions

    float div = clock_get_hz(clk_sys) / (freq * 10);
    sm_config_set_clkdiv(&c, div);

    pio_sm_init(pio, sm, offset, &c);
    pio_sm_set_enabled(pio, sm, true);
}

void put_pixel(uint32_t pixel_grb) {
    // Send to both LEDs (2 LEDs chained)
    pio_sm_put_blocking(pio0, 0, pixel_grb << 8u);
    sleep_us(10); // Small delay between pixels
    pio_sm_put_blocking(pio0, 0, pixel_grb << 8u);
    sleep_us(100); // Reset delay after last pixel
}

// --- Global Objects ---
OvenState ovenState; // Protected by mtx_OvenState
ReflowProfile currentProfile; // Global Profile Object

SystemConfig sysConfig;



// --- Mutexes & Queues ---
SemaphoreHandle_t mtx_SPI0 = NULL;
SemaphoreHandle_t mtx_I2C = NULL;
SemaphoreHandle_t mtx_OvenState = NULL;
SemaphoreHandle_t mtx_LVGL = NULL;

QueueHandle_t q_SensorData = NULL;
QueueHandle_t q_InputEvents = NULL;

// --- Interrupt Handling ---
volatile uint32_t last_irq_time = 0;

void gpio_callback(uint gpio, uint32_t events) {
    uint32_t now = to_ms_since_boot(get_absolute_time());
    if (now - last_irq_time < 50) return; // Simple debounce 50ms
    last_irq_time = now;
    
    InputEvent evt;
    evt.timestamp = now;
    evt.type = EVT_NONE;

    if (gpio == GPIO_BTN1) evt.type = EVT_BTN1_PRESS;
    else if (gpio == GPIO_BTN2) evt.type = EVT_BTN2_PRESS;

    else if (gpio == GPIO_ROT_BTN) evt.type = EVT_ENC_BTN_PRESS;
    else if (gpio == GPIO_ROT_DT) {
        // Encoder Logic (Simplified)
        if (gpio_get(GPIO_ROT_CLK)) evt.type = EVT_ENC_CCW;
        else evt.type = EVT_ENC_CW;
    } else if (gpio == GPIO_T1_ALT1) {
        // Safety Cutoff immediately (bypass queue for speed?)
        // Or just set state directly if mutex available.
        // Queue is safer for context.
        // Let's rely on vAlertHandlingTask polling software limit too.
        // But for hard interrupt:
        // Force state fault?
        // We can't take Mutex from ISR easily (xSemaphoreTakeFromISR).
        // Let's just log or set a volatile flag.
        // Ideally, we DISABLE HEATERS immediately here.
        gpio_put(GPIO_HEAT1, 0);
        gpio_put(GPIO_HEAT2, 0);
        // And send event? No input event for fault?
        // Let's make vAlertHandlingTask check the pin state too.
    }
    
    if (evt.type != EVT_NONE) {
        BaseType_t xHigherPriorityTaskWoken = pdFALSE;
        xQueueSendFromISR(q_InputEvents, &evt, &xHigherPriorityTaskWoken);
        portYIELD_FROM_ISR(xHigherPriorityTaskWoken);
    }
}

// --- Task Handles ---
TaskHandle_t hAlertTask = NULL;
TaskHandle_t hSensorTask = NULL;
TaskHandle_t hPIDTask = NULL;
TaskHandle_t hAppLogicTask = NULL;
TaskHandle_t hTFTDebugTask = NULL;

// --- Task Definitions ---

void vApplicationPassiveIdleHook(void) {
    // Required for SMP
}

// --- Task Functions (Core 0) ---

// --- SSR Control Logic ---
void vSSRControlTask(void *pvParameters) {
    (void)pvParameters;
    
    // Low Frequency PWM (e.g. 5Hz -> 200ms period)
    const int period_ticks = 10; // 10 * 20ms = 200ms window
    int tick_counter = 0;
    
    gpio_init(GPIO_HEAT1); gpio_set_dir(GPIO_HEAT1, GPIO_OUT);
    gpio_init(GPIO_HEAT2); gpio_set_dir(GPIO_HEAT2, GPIO_OUT);
    
    for (;;) {
        float p1 = 0, p2 = 0;
        if (xSemaphoreTake(mtx_OvenState, pdMS_TO_TICKS(10)) == pdTRUE) {
            p1 = ovenState.power_output_1; // 0-100
            p2 = ovenState.power_output_2;
            xSemaphoreGive(mtx_OvenState);
        }
        
        int threshold1 = (int)(p1 / 10.0f); // Map 0-100 to 0-10
        int threshold2 = (int)(p2 / 10.0f);
        
        gpio_put(GPIO_HEAT1, tick_counter < threshold1);
        gpio_put(GPIO_HEAT2, tick_counter < threshold2);
        
        tick_counter++;
        if (tick_counter >= period_ticks) tick_counter = 0;
        
        vTaskDelay(pdMS_TO_TICKS(20)); // 50Hz Loop
    }
}

// --- Helper to update Feedback ---
void update_feedback(OvenStateEnum state) {
    // LED Colors (GRB format) - BRIGHTER values
    uint32_t color = 0;
    switch (state) {
        case STATE_IDLE:     color = 0x00FF00; break; // Red (GRB: 0, 255, 0)
        case STATE_RUNNING:  color = 0x80FF00; break; // Orange (GRB: 128, 255, 0)
        case STATE_COOLDOWN: color = 0x0000FF; break; // Blue (GRB: 0, 0, 255)
        case STATE_FAULT:    color = 0x00FF00; break; // Red (fault = red)
        case STATE_INIT:     color = 0xFFFFFF; break; // White
        default:             color = 0; break;
    }
    put_pixel(color);
}

// Helper: Read MCP9600 temperature via raw I2C (register 0x00 = hot junction)
float read_mcp9600_temp(uint8_t addr) {
    uint8_t reg = 0x00; // Hot junction register
    uint8_t buf[2];
    
    int ret = i2c_write_blocking(I2C_PORT, addr, &reg, 1, true);
    if (ret < 0) return -999.0f;
    
    ret = i2c_read_blocking(I2C_PORT, addr, buf, 2, false);
    if (ret < 0) return -999.0f;
    
    // MCP9600: Upper byte is integer part, lower is fractional (0.0625 per bit)
    int16_t raw = (buf[0] << 8) | buf[1];
    return raw * 0.0625f;
}

// ============================================================
// === INPUT TASK (Polling & Events) ===
// ============================================================
void vInputTask(void *pvParameters) {
    (void)pvParameters;
    printf("[Input] Task started.\n");
    
    // Encoder State
    int last_clk = gpio_get(GPIO_ROT_CLK);
    static uint32_t last_enc_time = 0;
    
    // Button States (Active Low)
    int last_btn1 = 1;
    int last_btn2 = 1;

    int last_rot_btn = 1;
    
    for (;;) {
        uint32_t now = to_ms_since_boot(get_absolute_time());
        InputEvent evt;
        evt.timestamp = now;
        evt.type = EVT_NONE;
        
        // --- Button 1 ---
        int btn1 = gpio_get(GPIO_BTN1);
        if (btn1 == 0 && last_btn1 == 1) { // Pull-down Press? Or Pull-up? 
                                           // Board defined Input. Usually Pull-up -> 0 is press.
                                           // HW test showed 0=Pressed
             evt.type = EVT_BTN1_PRESS;
             play_tone(500, 50); // Audio Feedback
             xQueueSend(q_InputEvents, &evt, 0);
        }
        last_btn1 = btn1;
        
        // --- Button 2 ---
        int btn2 = gpio_get(GPIO_BTN2);
        if (btn2 == 0 && last_btn2 == 1) {
             evt.type = EVT_BTN2_PRESS;
             play_tone(500, 50);
             xQueueSend(q_InputEvents, &evt, 0);
        }
        last_btn2 = btn2;


        
        // --- Encoder Button ---
        int rot_btn = gpio_get(GPIO_ROT_BTN);
        if (rot_btn == 0 && last_rot_btn == 1) {
             evt.type = EVT_ENC_BTN_PRESS;
             play_tone(500, 50);
             xQueueSend(q_InputEvents, &evt, 0);
        }
        last_rot_btn = rot_btn;
        
        // --- Encoder Rotation ---
        int clk = gpio_get(GPIO_ROT_CLK);
        int dt = gpio_get(GPIO_ROT_DT);
        
        // Debounce 5ms
        if (clk != last_clk && (now - last_enc_time) > 5) {
            last_enc_time = now;
            // XOR logic: CLK == DT -> CCW, else CW
            if (clk == dt) {
                evt.type = EVT_ENC_CCW;
            } else {
                evt.type = EVT_ENC_CW;
            }
            // Send Encoder Event
            xQueueSend(q_InputEvents, &evt, 0);
            
            last_clk = clk;
        }
        
        // Poll Rate: 20Hz (50ms) is too slow for encoder? 
        // Encoder needs faster polling. 
        // 10ms (100Hz) might be okay for standard rotation, but 1-2ms is better.
        // HW test loop was 10Hz (100ms delay) + logic? No, check loop delay.
        // HW test loop had vTaskDelay(pdMS_TO_TICKS(100)) at end?
        // Wait, if HW test was 10Hz, encoder would be skipping like crazy!
        // Ah, vHardwareTestTask had `loop_count` check for temp, but `vTaskDelay` was 100ms? 
        // If so, the user rotated VERY slow.
        // I should increase poll rate for encoder reliability.
        vTaskDelay(pdMS_TO_TICKS(2)); // ~500Hz Polling
    }
}

void vFeedbackTask(void *pvParameters) {
    (void)pvParameters;
    
    printf("[Feedback] Task started. PIO already initialized in main().\\n");
    
    // PIO already initialized in main() - don't reinitialize!
    
    gpio_init(GPIO_BUZZER); gpio_set_dir(GPIO_BUZZER, GPIO_OUT);
    
    for (;;) {
        OvenStateEnum s = STATE_INIT;
        if (xSemaphoreTake(mtx_OvenState, pdMS_TO_TICKS(50)) == pdTRUE) {
            s = ovenState.state;
            if (s == STATE_FAULT) {
                 // Pulse 500Hz for 100ms
                 play_tone(100, 100); 
            } else {
                 gpio_put(GPIO_BUZZER, 0);
            }
            xSemaphoreGive(mtx_OvenState);
        }
        
        update_feedback(s);
        vTaskDelay(pdMS_TO_TICKS(200));
    }
}

void vAlertHandlingTask(void *pvParameters) {
    (void)pvParameters;
    TickType_t xLastWakeTime = xTaskGetTickCount();
    
    for (;;) {
        // High priority: check alerts, watchdog
        // In real hardware, we would check GPIO_T1_ALT1, etc.
        
        float current_t1 = 0;
        if (xSemaphoreTake(mtx_OvenState, pdMS_TO_TICKS(10)) == pdTRUE) {
            current_t1 = ovenState.current_temp_t1;
            
            // Software Limit Check
            if (current_t1 > 260.0f) {
                ovenState.state = STATE_FAULT;
                ovenState.fault_active = true;
                ovenState.power_output_1 = 0;
                printf("!!! OVERTEMP FAULT !!!\n");
            }
            xSemaphoreGive(mtx_OvenState);
        }
        
        vTaskDelayUntil(&xLastWakeTime, pdMS_TO_TICKS(100)); // 10Hz safety check
    }
}

// --- MCP9600 Interface ---
// --- Legacy Sensor Drivers Removed (Using direct I2C) ---
// MCP9600 is handled via read_mcp9600_temp()
// DS18B20 is removed/disabled as per request (AUX not connected)

void vSensorPollerTask(void *pvParameters) {
    (void)pvParameters;
    TickType_t xLastWakeTime = xTaskGetTickCount();
    
    // Initial Setup
    // Raw I2C used, no specific setup_sensors() needed.
    // I2C bus init happens in main().
    
    uint32_t log_counter = 0;

    for (;;) {
        // 1. Read MCP9600 (I2C) - Fast (approx 5-10ms)
        if (xSemaphoreTake(mtx_I2C, pdMS_TO_TICKS(20)) == pdTRUE) {
            float t = read_mcp9600_temp(I2C_ADDR_MCP9600_T1);
            
            // Check for error (e.g. -999.0f)
            if (t > -100.0f) {
                 if (xSemaphoreTake(mtx_OvenState, pdMS_TO_TICKS(5)) == pdTRUE) {
                    ovenState.current_temp_t1 = t;
                    xSemaphoreGive(mtx_OvenState);
                 }
                 if (log_counter++ % 10 == 0) { // Log every 2s
                     printf("[Sensors] T1: %.2f C\n", t);
                 }
            } else {
                 printf("[Sensors] MCP9600 Read Failed\n");
            }
            xSemaphoreGive(mtx_I2C);
        }
        
        // Loop at 5Hz (200ms)
        vTaskDelayUntil(&xLastWakeTime, pdMS_TO_TICKS(200));
    }
}
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
int main() {
    stdio_init_all();
    
    // Wait for USB serial connection
    sleep_ms(2000);
    
    printf("\n\n");
    printf("========================================\n");
    printf("   MTR REFLOW OVEN - STARTING UP\n");
    printf("========================================\n");
    printf("\n");

    // --- HW Init ---
    // Initialize I2C
    printf("[I2C] Initializing I2C0 on GPIO %d (SDA) / %d (SCL)...\n", GPIO_I2C_SDA, GPIO_I2C_SCL);
    i2c_init(I2C_PORT, 100 * 1000); // Lowered to 100kHz for reliability
    gpio_set_function(GPIO_I2C_SDA, GPIO_FUNC_I2C);
    gpio_set_function(GPIO_I2C_SCL, GPIO_FUNC_I2C);
    gpio_pull_up(GPIO_I2C_SDA);
    gpio_pull_up(GPIO_I2C_SCL);
    printf("[I2C] I2C initialized at 100kHz\n");
    
    // === I2C BUS SCAN ===
    printf("\n[I2C] Scanning I2C bus...\n");
    printf("     0  1  2  3  4  5  6  7  8  9  A  B  C  D  E  F\n");
    for (int addr_base = 0; addr_base < 128; addr_base += 16) {
        printf("%02X: ", addr_base);
        for (int addr_offset = 0; addr_offset < 16; addr_offset++) {
            int addr = addr_base + addr_offset;
            if (addr < 0x08 || addr > 0x77) {
                printf("   ");
            } else {
                uint8_t rxdata;
                int ret = i2c_read_blocking(I2C_PORT, addr, &rxdata, 1, false);
                if (ret >= 0) {
                    printf("%02X ", addr);
                } else {
                    printf("-- ");
                }
            }
        }
        printf("\n");
    }
    printf("[I2C] Scan complete\n\n");
    
    // === GPIO DEBUG TEST ===
    printf("[GPIO] Initializing buttons and encoder...\n");
    gpio_init(GPIO_BTN1); gpio_set_dir(GPIO_BTN1, GPIO_IN); gpio_pull_up(GPIO_BTN1);
    gpio_init(GPIO_BTN2); gpio_set_dir(GPIO_BTN2, GPIO_IN); gpio_pull_up(GPIO_BTN2);

    gpio_init(GPIO_ROT_BTN); gpio_set_dir(GPIO_ROT_BTN, GPIO_IN); gpio_pull_up(GPIO_ROT_BTN);
    gpio_init(GPIO_ROT_DT);  gpio_set_dir(GPIO_ROT_DT,  GPIO_IN); gpio_pull_up(GPIO_ROT_DT);
    gpio_init(GPIO_ROT_CLK); gpio_set_dir(GPIO_ROT_CLK, GPIO_IN); gpio_pull_up(GPIO_ROT_CLK);
    
    // Read initial button states
    printf("[GPIO] Button states: BTN1=%d BTN2=%d ROT_BTN=%d\n",
           gpio_get(GPIO_BTN1), gpio_get(GPIO_BTN2), gpio_get(GPIO_ROT_BTN));
    printf("[GPIO] Encoder: CLK=%d DT=%d\n", gpio_get(GPIO_ROT_CLK), gpio_get(GPIO_ROT_DT));
    
    // === BUZZER TEST ===
    printf("\n[BUZZER] Testing buzzer on GPIO %d...\n", GPIO_BUZZER);
    gpio_init(GPIO_BUZZER);
    gpio_set_dir(GPIO_BUZZER, GPIO_OUT);
    // === BUZZER TEST (500Hz confirmed loudest) ===
    printf("\n[BUZZER] Testing buzzer on GPIO %d (500Hz)...\n", GPIO_BUZZER);
    gpio_init(GPIO_BUZZER);
    gpio_set_dir(GPIO_BUZZER, GPIO_OUT);
    gpio_set_drive_strength(GPIO_BUZZER, GPIO_DRIVE_STRENGTH_12MA);
    
    // Play "OK" pattern: 3 short beeps
    play_tone(500, 100); sleep_ms(100);
    play_tone(500, 100); sleep_ms(100);
    play_tone(500, 100);
    printf("[BUZZER] Startup tones complete\n");
    
    // === SD CARD TEST ===
    test_sd_card();
    
    // === SSR TEST ===
    printf("\n[SSR] Testing SSR outputs on GPIO %d and %d...\n", GPIO_HEAT1, GPIO_HEAT2);
    gpio_init(GPIO_HEAT1);
    gpio_init(GPIO_HEAT2);
    gpio_set_dir(GPIO_HEAT1, GPIO_OUT);
    gpio_set_dir(GPIO_HEAT2, GPIO_OUT);
    gpio_put(GPIO_HEAT1, 0);
    gpio_put(GPIO_HEAT2, 0);
    printf("[SSR] SSRs initialized (OFF)\n");
    
    // LED Test removed (WS2812B handled by vFeedbackTask)


    // SPI Init / LCD Init removed (handled by hagl_init in vUITask)
    printf("Skipping Raw SPI Test.\n");

    
    // SPI Init handled by hagl_init() later
    // Interrupts handled by vInputTask (Polling)
    
    // --- FreeRTOS Objects ---
    mtx_SPI0 = xSemaphoreCreateMutex();
    mtx_I2C = xSemaphoreCreateMutex();
    mtx_OvenState = xSemaphoreCreateMutex();
    mtx_LVGL = xSemaphoreCreateMutex();
    
    q_SensorData = xQueueCreate(5, sizeof(SensorData));
    q_InputEvents = xQueueCreate(10, sizeof(InputEvent));
    
    // Default State Init
    ovenState.state = STATE_INIT;
    ovenState.t2_connected = false;
    ovenState.fault_active = false;
    
    // --- Initial File System Mount ---
    // Note: SD Card shares SPI with TFT. Need proper CS management?
    // FatFs usually handles low-level SPI if configured correctly.
    // For now, we assume standard mounting logic.
    /*
    if (f_mount(&fs, "", 1) == FR_OK) {
        sd_mounted = true;
        load_system_config();
        // pre-load default profile?
        load_profile("/profiles/sac305.json");
    } else {
        printf("SD Mount Failed!\n");
        // Fallback defaults
        init_test_profile();
    }
    */
    init_test_profile(); // Defaulting for now until SD HW verified

    // --- Interrupts (DISABLED - Using vInputTask Polling) ---
    // gpio_set_irq_enabled_with_callback(GPIO_BTN1, GPIO_IRQ_EDGE_RISE | GPIO_IRQ_EDGE_FALL, true, &gpio_callback);
    // gpio_set_irq_enabled(GPIO_BTN2, GPIO_IRQ_EDGE_RISE | GPIO_IRQ_EDGE_FALL, true);

    // gpio_set_irq_enabled(GPIO_ROT_BTN, GPIO_IRQ_EDGE_RISE | GPIO_IRQ_EDGE_FALL, true);
    // gpio_set_irq_enabled(GPIO_ROT_DT, GPIO_IRQ_EDGE_RISE | GPIO_IRQ_EDGE_FALL, true);
    // gpio_set_irq_enabled(GPIO_T1_ALT1, GPIO_IRQ_EDGE_FALL, true);
    
    // --- Create Tasks ---
    
    // Core 0 Tasks
    xTaskCreate(vAppLogicTask, "AppLogic", 2048, NULL, 3, &hAppLogicTask);
    xTaskCreate(vSensorPollerTask, "Sensors", 1024, NULL, 2, NULL); 
    // xTaskCreate(vAuxiliaryTask, "AuxSensors", 1024, NULL, 1, NULL); // DISABLED - DS18B20 not connected
    xTaskCreate(vPIDLoopTask, "PID", 1024, NULL, 2, &hPIDTask);
    xTaskCreate(vAlertHandlingTask, "Alerts", 512, NULL, 5, &hAlertTask);
    
    // Input Task (Polling)
    xTaskCreate(vInputTask, "Input", 1024, NULL, 3, NULL);
    
    // Output Tasks
    xTaskCreate(vSSRControlTask, "SSR_PWM", 512, NULL, 4, NULL);
    xTaskCreate(vFeedbackTask, "Feedback", 512, NULL, 2, NULL);

    // Core 1 (UI)
    // Note: Display is not working yet, but task structure is preserved.
    xTaskCreate(vUITask, "UI_Manager", 2048, NULL, 2, &hTFTDebugTask);
    
    // Pinning example (if supported):
    // vTaskCoreAffinitySet(hTFTDebugTask, (1 << 1)); // Pin to Core 1
    // vTaskCoreAffinitySet(hAlertTask, (1 << 0));    // Pin to Core 0
    
    // Initialize TFT before scheduler to ensure hardware is ready ? 
    // Or protect with Mutex. TFT_eSPI init isn't thread safe usually.
    // Better to init here.
    // tft.init();
    // tft.setRotation(1); // Landscape
    // tft.fillScreen(TFT_BLUE);
    // tft.setCursor(10, 10);
    // tft.println("Booting...");

    // Start scheduler (never returns)
    printf("Starting Scheduler...\n");
    vTaskStartScheduler();

    while (true) {
        // Should not reach here
        tight_loop_contents();
    }
}

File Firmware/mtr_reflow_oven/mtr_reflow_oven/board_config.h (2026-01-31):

#ifndef BOARD_CONFIG_H
#define BOARD_CONFIG_H

// --- Inputs (Control Panel) ---
#define GPIO_BTN1      0  // Input (Confirm/Start)
#define GPIO_BTN2      1  // Input (Stop/Back)

#define GPIO_SD_CD     3  // Input (SD Card Detect)

// --- I2C Bus (Sensors) ---
#define GPIO_I2C_SDA   4
#define GPIO_I2C_SCL   5
#define I2C_PORT       i2c0
#define I2C_ADDR_MCP9600_T1 0x60 // Default address for Sensor 1
#define I2C_ADDR_MCP9600_T2 0x67 // Default address for Sensor 2 (if present)

// --- Rotary Encoder ---
#define GPIO_ROT_DT    6
#define GPIO_ROT_CLK   7
#define GPIO_ROT_BTN   8

// --- Status LEDs ---
#define GPIO_WS_LED    9  // WS2812B Data

// --- MCP9600 Alerts (Sensor 1) ---
#define GPIO_T1_ALT4   10
#define GPIO_T1_ALT3   11
#define GPIO_T1_ALT2   12
#define GPIO_T1_ALT1   13

// --- MCP9600 Alerts (Sensor 2) ---
#define GPIO_T2_ALT4   14
#define GPIO_T2_ALT3   15
#define GPIO_T2_ALT2   16
#define GPIO_T2_ALT1   17

// --- SPI Bus (Screen + SD) ---
#define GPIO_SPI_SCK   18
#define GPIO_SPI_MOSI  19
#define GPIO_SPI_MISO  20
#define SPI_PORT       spi0

// --- Chip Selects & Control ---
#define GPIO_SCR_CS    21
#define GPIO_SD_CS     22
#define GPIO_SCR_BL    23 // PWM
#define GPIO_SCR_RST   24
#define GPIO_SCR_DC    25

// --- Power Outputs (SSRs) ---
#define GPIO_HEAT1     26 // PWM (SSR 1)
#define GPIO_HEAT2     27 // PWM (SSR 2)

// --- Audio ---
#define GPIO_BUZZER    28 // PWM

// --- 1-Wire ---
#define GPIO_ONE_WIRE  29


#endif // BOARD_CONFIG_H
